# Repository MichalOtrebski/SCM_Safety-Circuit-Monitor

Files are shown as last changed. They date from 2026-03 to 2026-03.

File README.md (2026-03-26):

# SCM - Safety Circuit Monitor
A Circuit that monitors the Safety Circuit on an FS car and toggles LEDs for the most upstream failure point.

## Detailed Description

The purpose of this device is to display to the driver the current state of the Safety system. The safety system is a set of switches and devices which ensure safe operation and shutdown of the car under specific circumstances, once one of these devices is triggered its important for the driver and any technicians to be aware of where exactly the problem is.

## Working Principle

By monitoring various points along the circuit we can determine the most upstream failure point. The Safety Circuit works by driving 12V through various devices in series, the output of the entire stream feeds into automotive relays which then enable power delivery to critial automotive systems such as the ignition coils, fuel pump, and injectors.

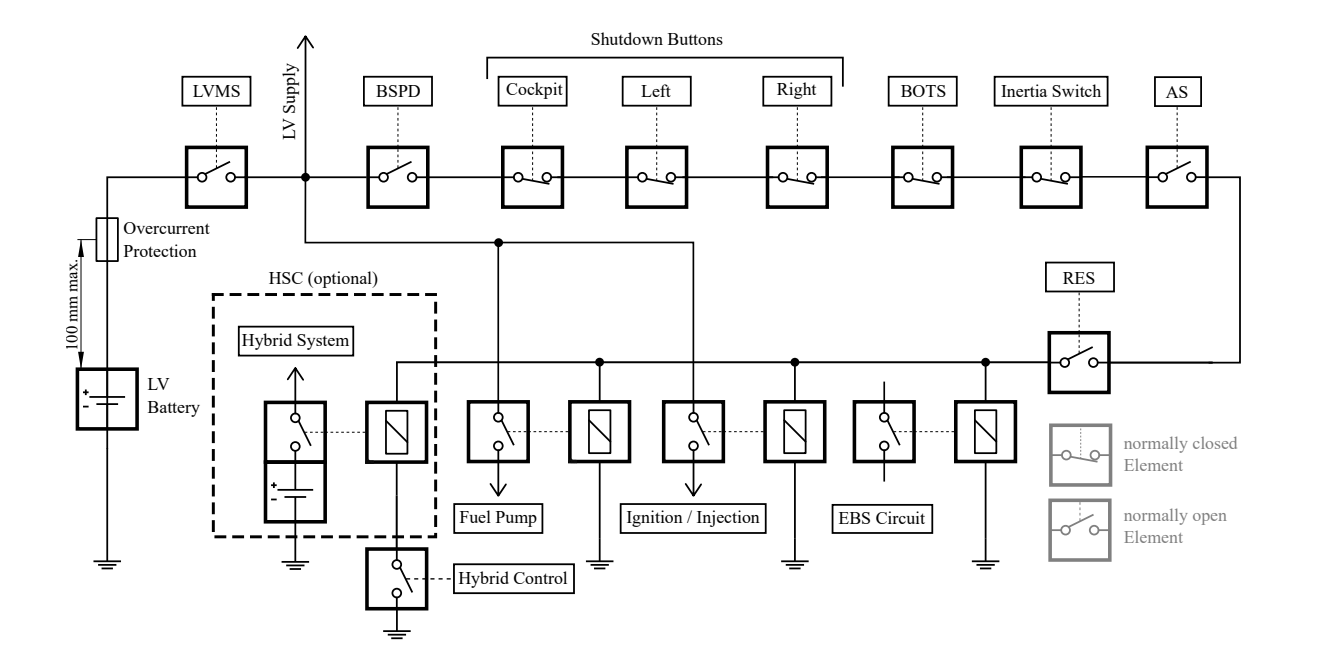
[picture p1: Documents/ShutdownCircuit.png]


So by monitoring the input and output of each device we can determine if 12V is entering the device and if 12V is being output, if a device is not outputing 12V while its input is active then we know that the device has been triggered.

### Signals

The signals we monitor are:

- **BSPD** (Brake System Plausability Device)
- **Inertia** Switch
- **BOTS** (Brake Over Travel Switch)
- **Cockpit** Shutdown Button
- **Left** Shutdown Button
- **Right** Shutdown Button

Hence the Circuit will require six monitoring circut, each looking at the input and output of one device, however since the devices are in series the output of one device is also the input of the next one. 

## Schematic

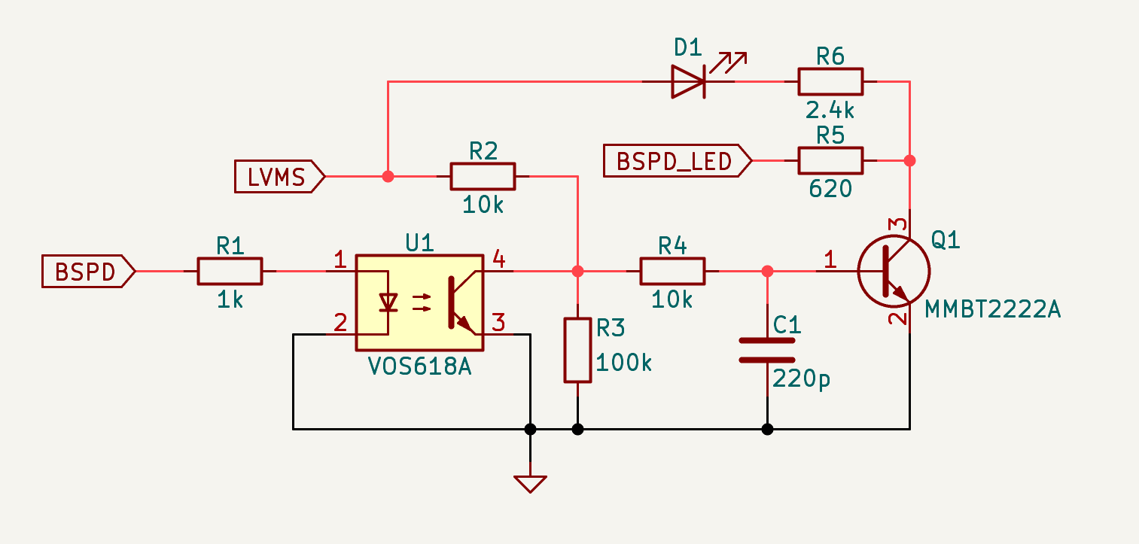
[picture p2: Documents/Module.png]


Each module monitors the input of a device and its output, the basic function is that we use an optocoupler with a pullup, the input of a device acts also as the power source for the module. If we have 12V input into the system we will have a pullup on the output of the optocoupler, which will feed the BJT and sink the external and internal LEDs, showing an error. However if we also have 12V at the output then the pull up sinks to ground via the optocoupler. 

Since the devices are in series, downstream devices wont get any power and no LEDs will be turned on, effectively the system will only light up the most upstream failure point so the driver can focus on reseting it.

## Design Choices

**VOS618A**
- We se an optocoupler to galvanically isolate the input and output between the device, any failure here could bypass the safety device and bring power to the car.
- We use the VOS618A for its high isolation, suitable CTR, and common/cheap availability.

**MMBT2222A**
- We use the BJT here as the driver for the LEDs, sinking their high current.
- we use the MMBT2222A specifically due to its high sinking capacity (600mA & 300mW).z

## Potential Future Revisions

- Increase of possible devices for future safety systems with more than six devices.
- Decrease power consumption (mainly from constantly sinking current through the optocoupler during normal operation)
- adjustable resistor values for varying external LEDs??

## Changelog

**V1.0**
- Initial Design
- Complete Schematic
- Routed PCB
- Verified Behaviour

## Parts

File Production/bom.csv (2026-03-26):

Designator | Footprint | Quantity | Value | LCSC Part #
C1, C2, C3, C4, C5, C6 | 0805 | 6 | 220p
D1, D2, D3, D4, D5, D6 | 0603 | 6 | LED
J1, J2 | TerminalBlock_TE_282834-7_1x07_P2.54mm_Horizontal | 2 | Screw_Terminal_01x07
Q1, Q2, Q3, Q4, Q5, Q6 | SOT-23 | 6 | MMBT2222A
R1, R13, R19, R20, R21, R7 | 0805 | 6 | 1k
R10, R14, R16, R2, R22, R23, R24, R28, R29, R30, R4, R8 | 0805 | 12 | 10k
R11, R17, R31, R33, R35, R6 | 0805 | 6 | 2.4k
R12, R18, R32, R34, R36, R5 | R_Axial_DIN0207_L6.3mm_D2.5mm_P7.62mm_Horizontal | 6 | 620
R15, R25, R26, R27, R3, R9 | 0805 | 6 | 100k
U1, U2, U3, U4, U5, U6 | SSOP-4_4.4x2.6mm_P1.27mm | 6 | VOS618A

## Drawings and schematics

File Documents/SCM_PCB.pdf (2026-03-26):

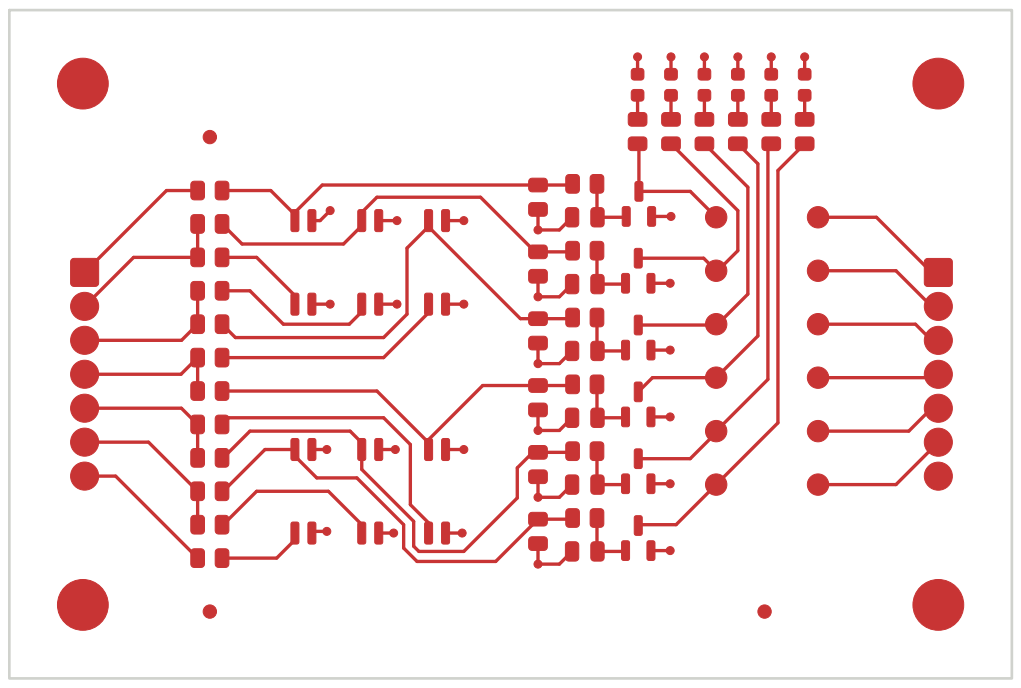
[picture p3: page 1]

Id: 1/2 Title: File: SCM.kicad_pcb Sheet:

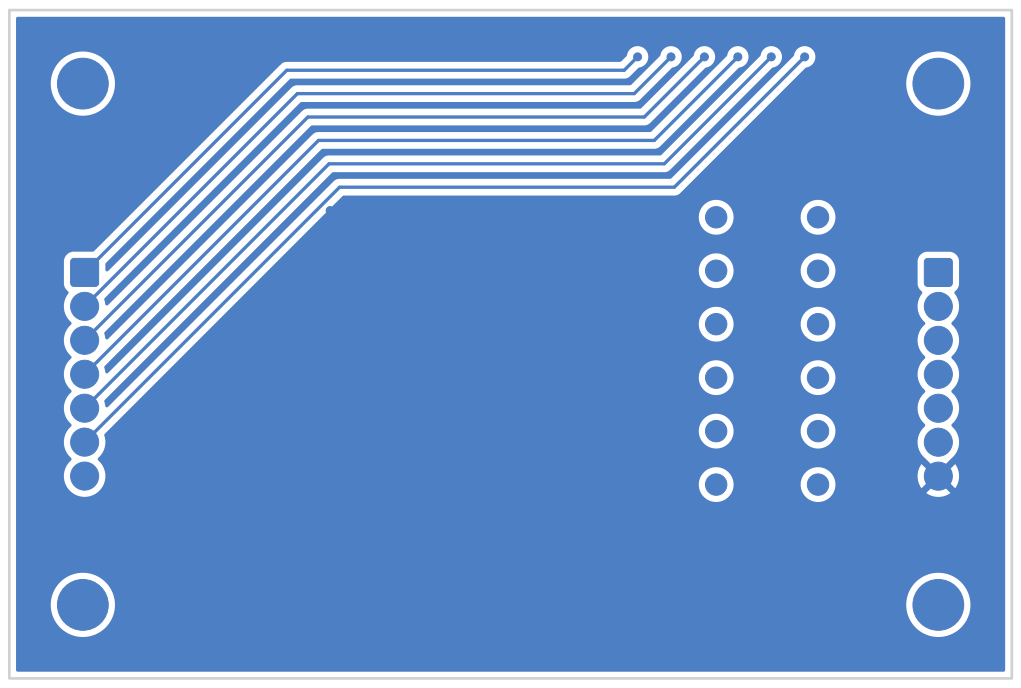
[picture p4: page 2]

Id: 2/2 Title: File: SCM.kicad_pcb Sheet:

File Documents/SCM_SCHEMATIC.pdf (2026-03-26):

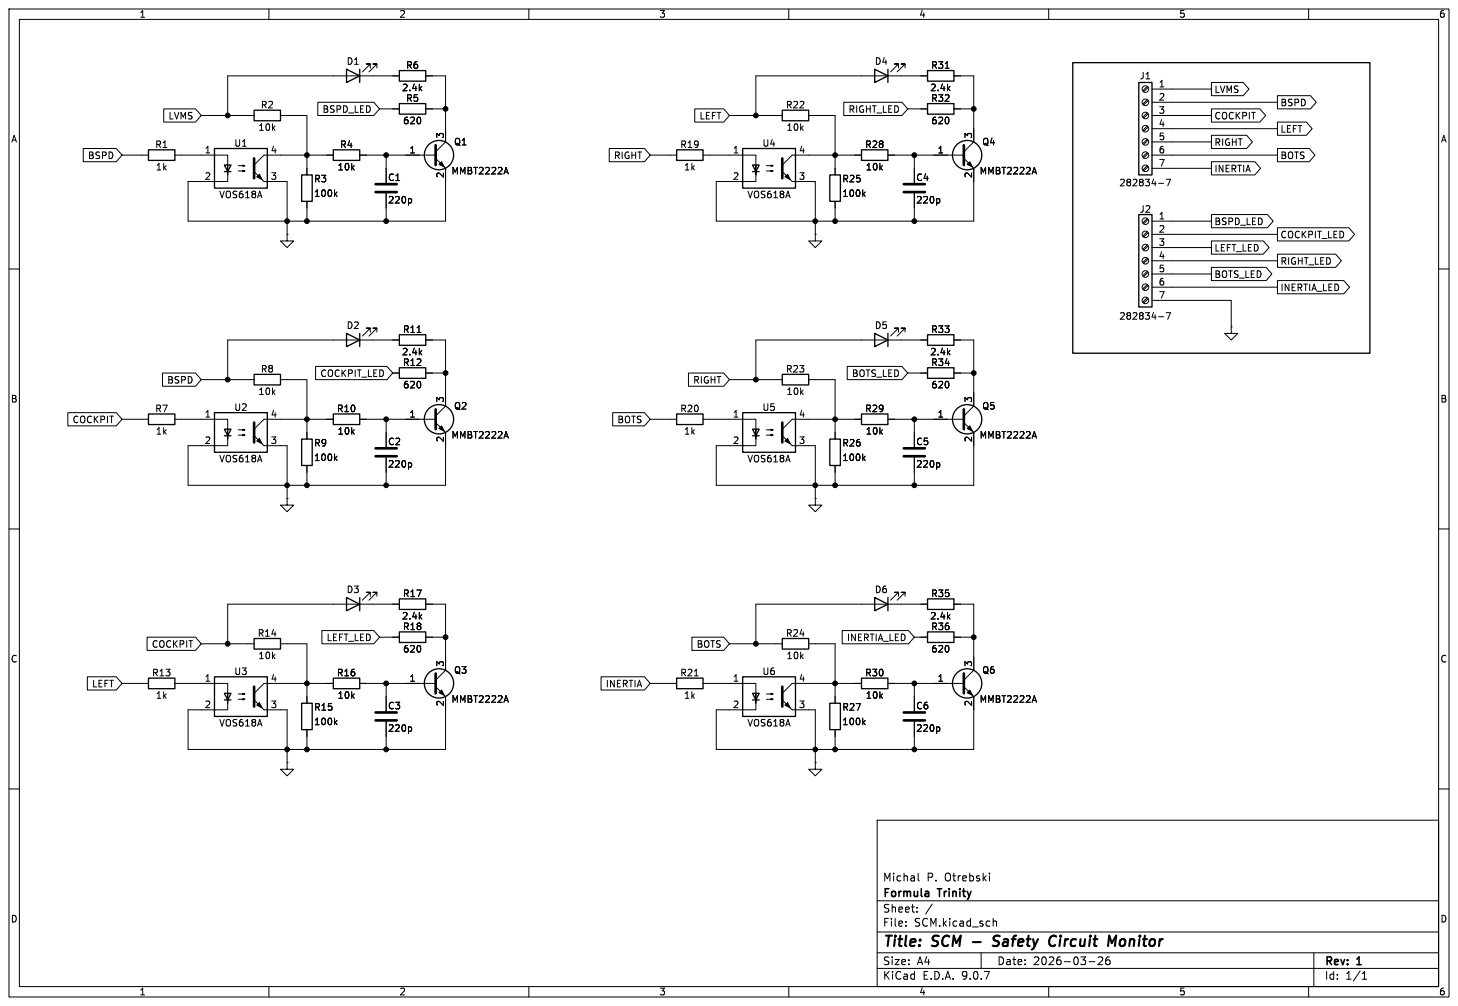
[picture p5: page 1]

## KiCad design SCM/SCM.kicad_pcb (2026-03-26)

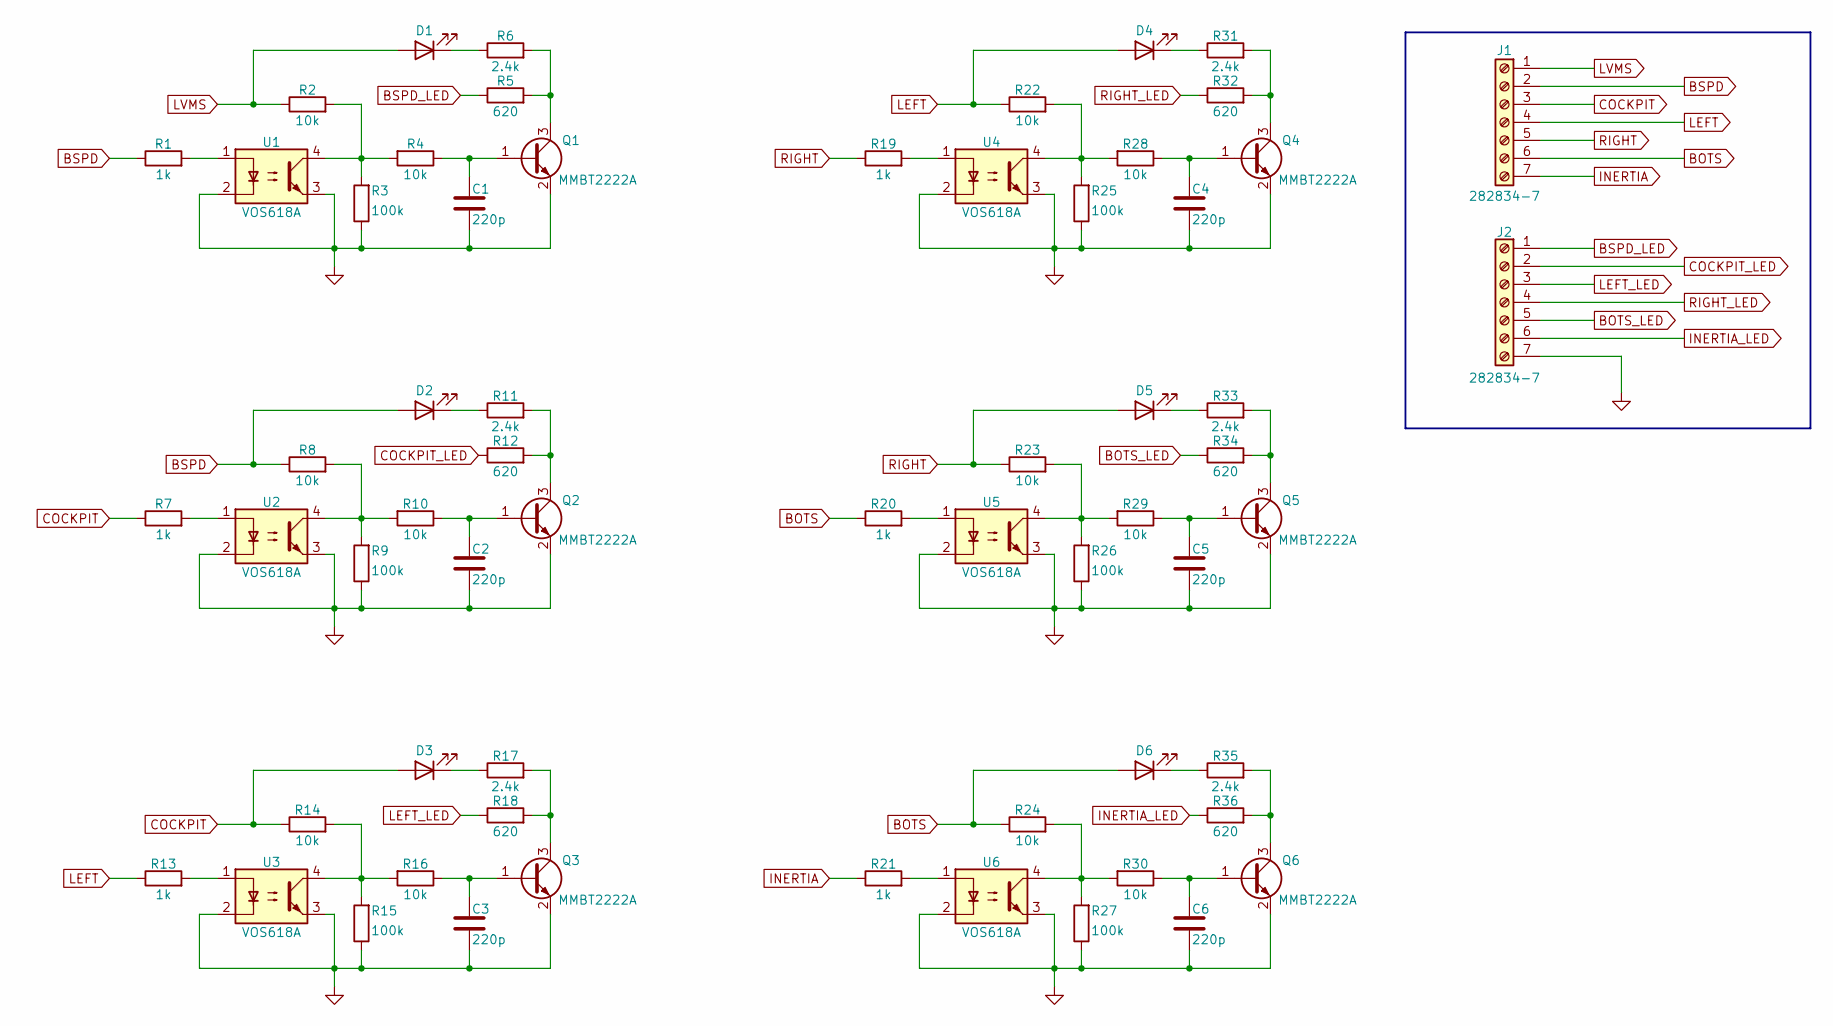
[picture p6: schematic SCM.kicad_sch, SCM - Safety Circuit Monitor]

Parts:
C1, C2, C3, C4, C5, C6: 220p; C_0805_2012Metric
D1, D2, D3, D4, D5, D6: LED; LED_0603_1608Metric
J1, J2: 282834-7; TerminalBlock_TE_282834-7_1x07_P2.54mm_Horizontal
Q1, Q2, Q3, Q4, Q5, Q6: MMBT2222A; SOT-23
R1, R7, R13, R19, R20, R21: 1k; R_0805_2012Metric
R2, R4, R8, R10, R14, R16, R22, R23, R24, R28, R29, R30: 10k; R_0805_2012Metric
R3, R9, R15, R25, R26, R27: 100k; R_0805_2012Metric
R5, R12, R18, R32, R34, R36: 620; R_Axial_DIN0207_L6.3mm_D2.5mm_P7.62mm_Horizontal
R6, R11, R17, R31, R33, R35: 2.4k; R_0805_2012Metric
U1, U2, U3, U4, U5, U6: VOS618A; SSOP-4_4.4x2.6mm_P1.27mm

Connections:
BOTS: D6.2 (A), J1.6, R20.1, R24.1
BOTS_LED: J2.5, R34.1
BSPD: D2.2 (A), J1.2, R1.1, R8.1
BSPD_LED: J2.1, R5.1
COCKPIT: D3.2 (A), J1.3, R7.1, R14.1
COCKPIT_LED: J2.2, R12.1
GND: C1.2, C2.2, C3.2, C4.2, C5.2, C6.2, J2.7, Q1.2 (E), Q2.2 (E), Q3.2 (E), Q4.2 (E), Q5.2 (E), Q6.2 (E), R3.1, R9.1, R15.1, R25.1, R26.1, R27.1, U1.2, U1.3, U2.2, U2.3, U3.2, U3.3, U4.2, U4.3, U5.2, U5.3, U6.2, U6.3
INERTIA: J1.7, R21.1
INERTIA_LED: J2.6, R36.1
LEFT: D4.2 (A), J1.4, R13.1, R22.1
LEFT_LED: J2.3, R18.1
LVMS: D1.2 (A), J1.1, R2.1
unnamed: D1.1 (K), R6.1
unnamed: D2.1 (K), R11.1
unnamed: D3.1 (K), R17.1
unnamed: D4.1 (K), R31.1
unnamed: D5.1 (K), R33.1
unnamed: D6.1 (K), R35.1
unnamed: C1.1, Q1.1 (B), R4.1
unnamed: Q1.3 (C), R5.2, R6.2
unnamed: C2.1, Q2.1 (B), R10.1
unnamed: Q2.3 (C), R11.2, R12.2
unnamed: C3.1, Q3.1 (B), R16.1
unnamed: Q3.3 (C), R17.2, R18.2
unnamed: C4.1, Q4.1 (B), R28.1
unnamed: Q4.3 (C), R31.2, R32.2
unnamed: C5.1, Q5.1 (B), R29.1
unnamed: Q5.3 (C), R33.2, R34.2
unnamed: C6.1, Q6.1 (B), R30.1
unnamed: Q6.3 (C), R35.2, R36.2
unnamed: R1.2, U1.1
unnamed: R2.2, R3.2, R4.2, U1.4
unnamed: R7.2, U2.1
unnamed: R8.2, R9.2, R10.2, U2.4
unnamed: R13.2, U3.1
unnamed: R14.2, R15.2, R16.2, U3.4
unnamed: R19.2, U4.1
unnamed: R20.2, U5.1
unnamed: R21.2, U6.1
unnamed: R22.2, R25.2, R28.2, U4.4
unnamed: R23.2, R26.2, R29.2, U5.4
unnamed: R24.2, R27.2, R30.2, U6.4
RIGHT: D5.2 (A), J1.5, R19.1, R23.1
RIGHT_LED: J2.4, R32.1

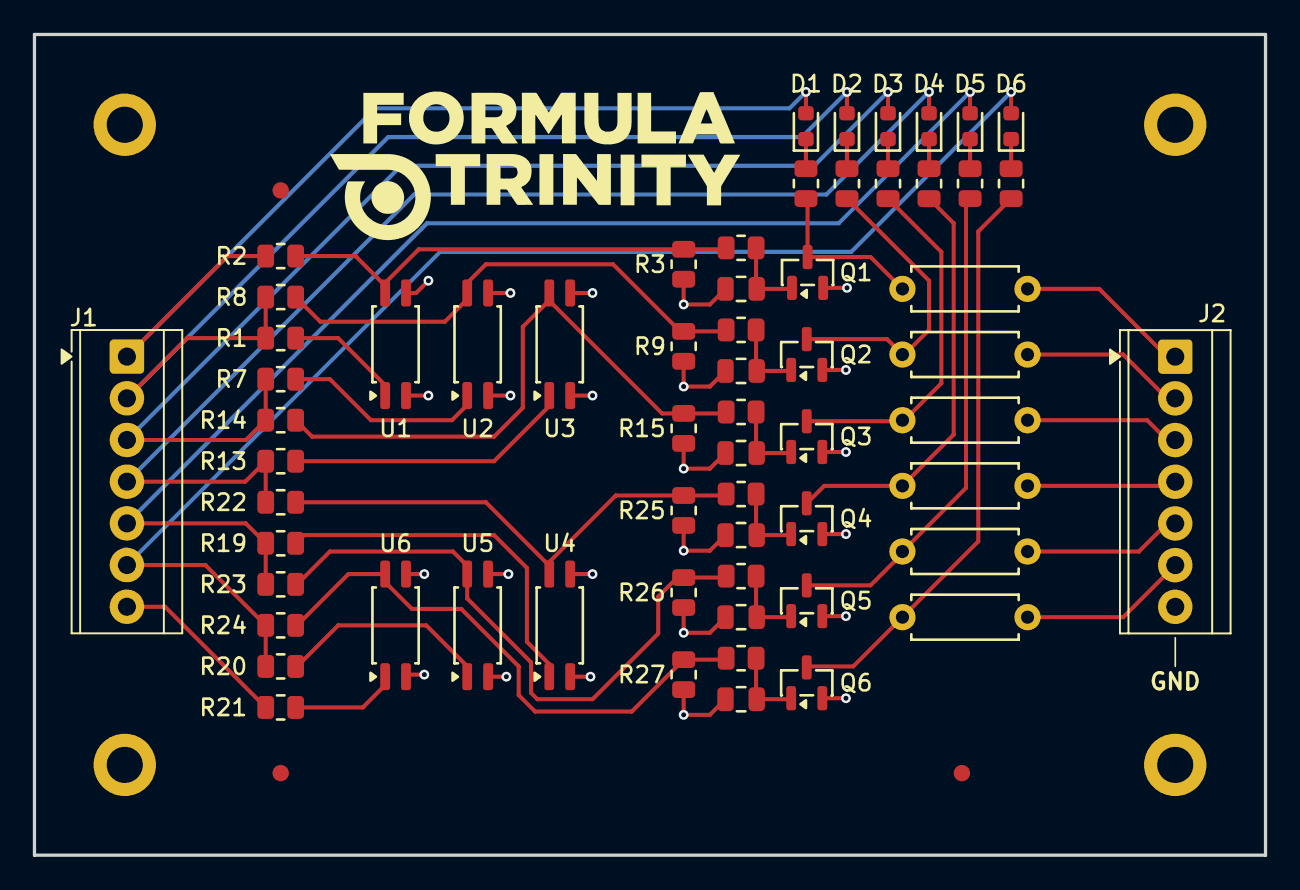
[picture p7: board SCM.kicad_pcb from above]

Board: 2 copper layers, 75.0 x 50.0 mm, 62 parts (0 on the bottom side), 44 nets.
